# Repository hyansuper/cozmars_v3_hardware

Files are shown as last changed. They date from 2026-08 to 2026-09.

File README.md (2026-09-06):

- 3D model online preview: https://a360.co/4c95q6T
- PCB schematic and layout: https://oshwhub.com/hyan/project_uewvqdli
    - the antenna is not tuned for optimal, but it works somehow
    - PCB is 4-layered, 1.2 mm thick
- Electronics:
    - 头部主控是 ESP32-S3R8，底板 ESP32-C3N4 辅助，USB 正反接分别连接两个芯片
    - PCB 间用 SH1.0mm 导线连接，有些是两头同向，有些是两头反向，注意看 PCB 自行判断
    - 普通蓝色 180° 舵机，把两耳朵剪掉
    - GM12-N10 马达，短轴
    - 后轮用 8x4x14mm 轴承
    - GC0308 摄像头，其他型号因该也可以用，推荐 120° 广角
    - 50x30x40 锂电池，注意正负极
    - 3012 小扬声器

TODO: 
    use shorter wires and smaller connectors for the servos

LICENSE: TAPR Open Hardware License

firmware: https://github.com/hyansuper/cozmars.git

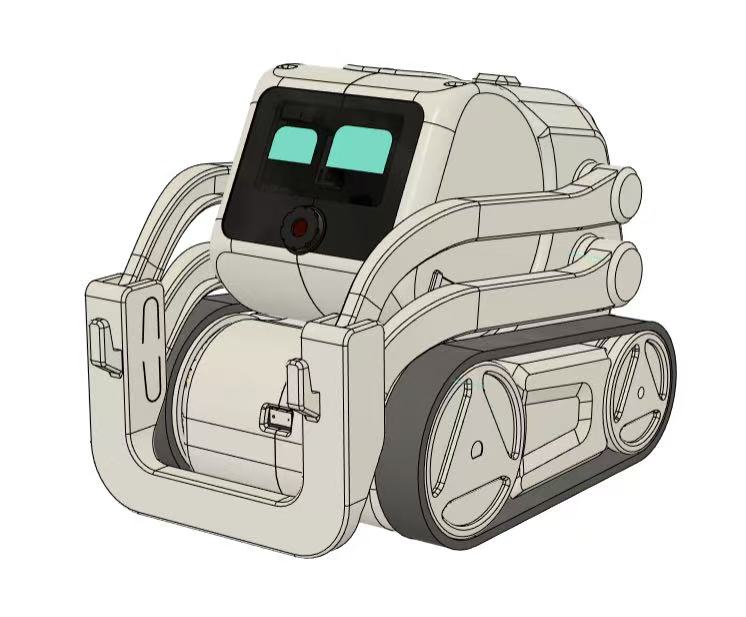
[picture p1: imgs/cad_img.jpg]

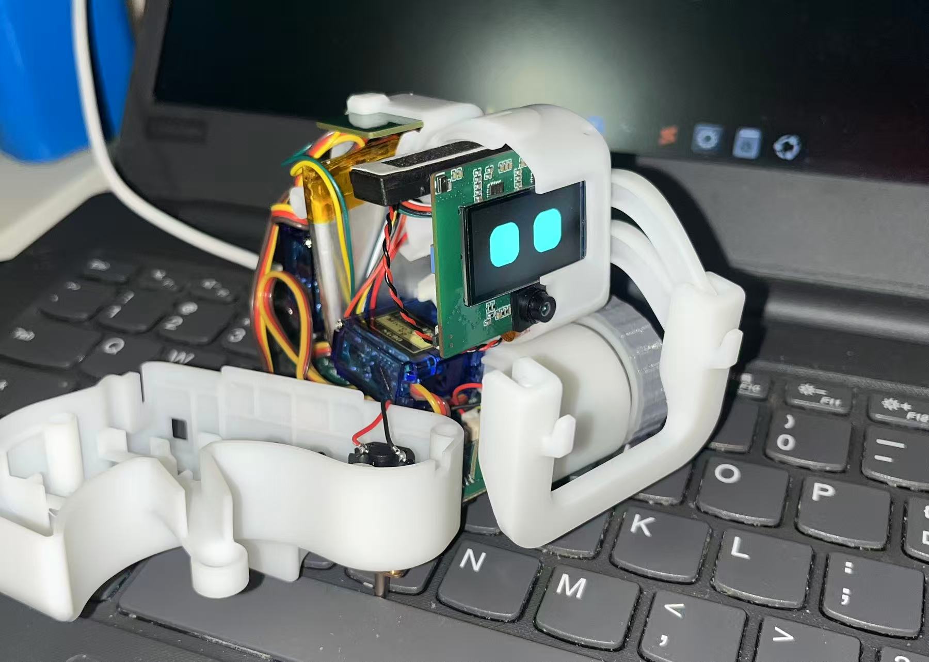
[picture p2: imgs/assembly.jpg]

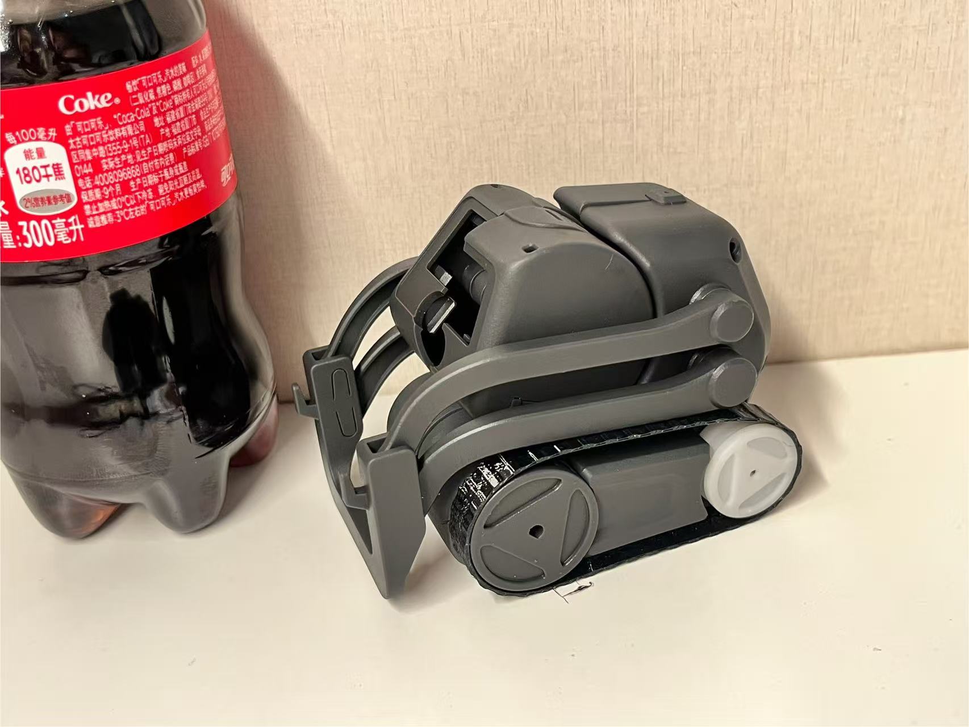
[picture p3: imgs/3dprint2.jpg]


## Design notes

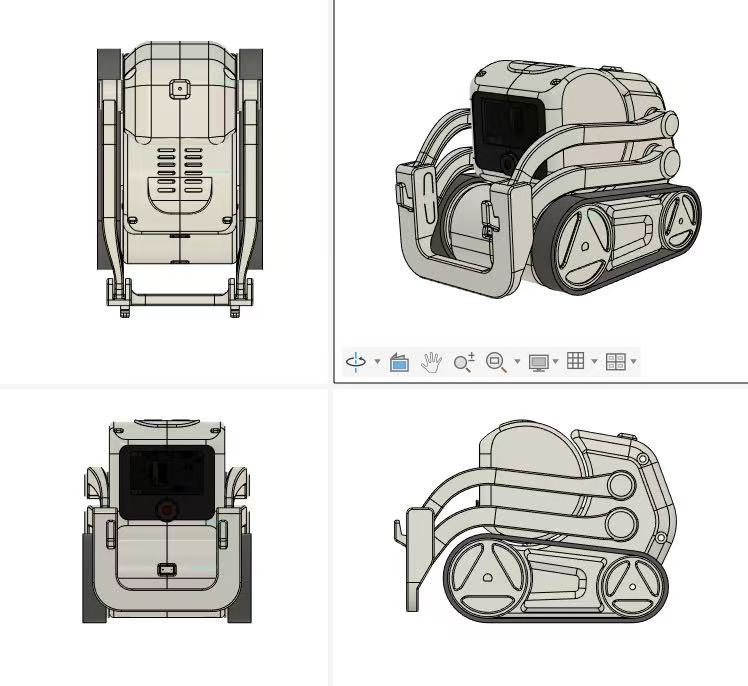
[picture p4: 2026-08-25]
imgs/cad_img3.jpg

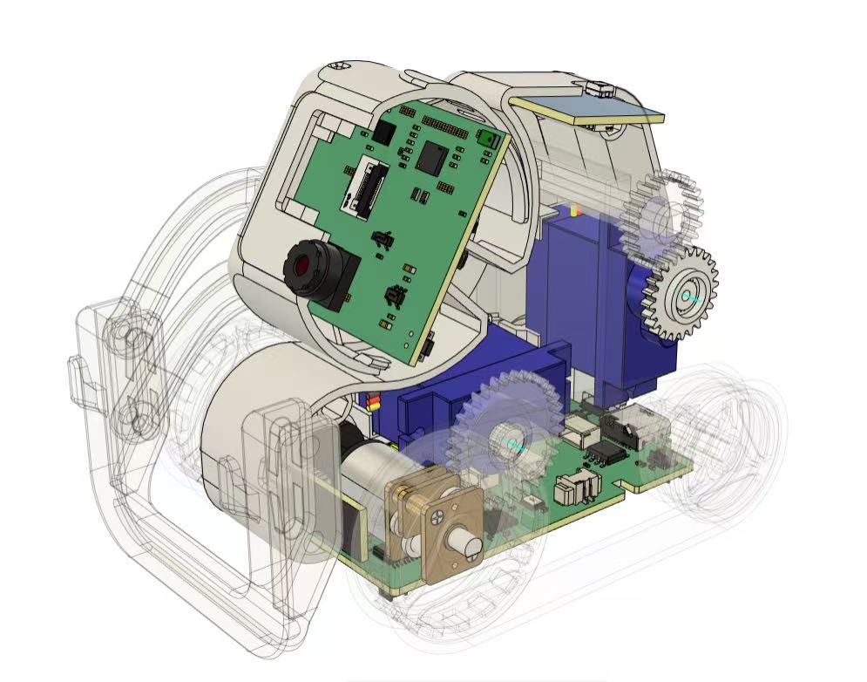
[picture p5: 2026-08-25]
imgs/cad_img2.jpg

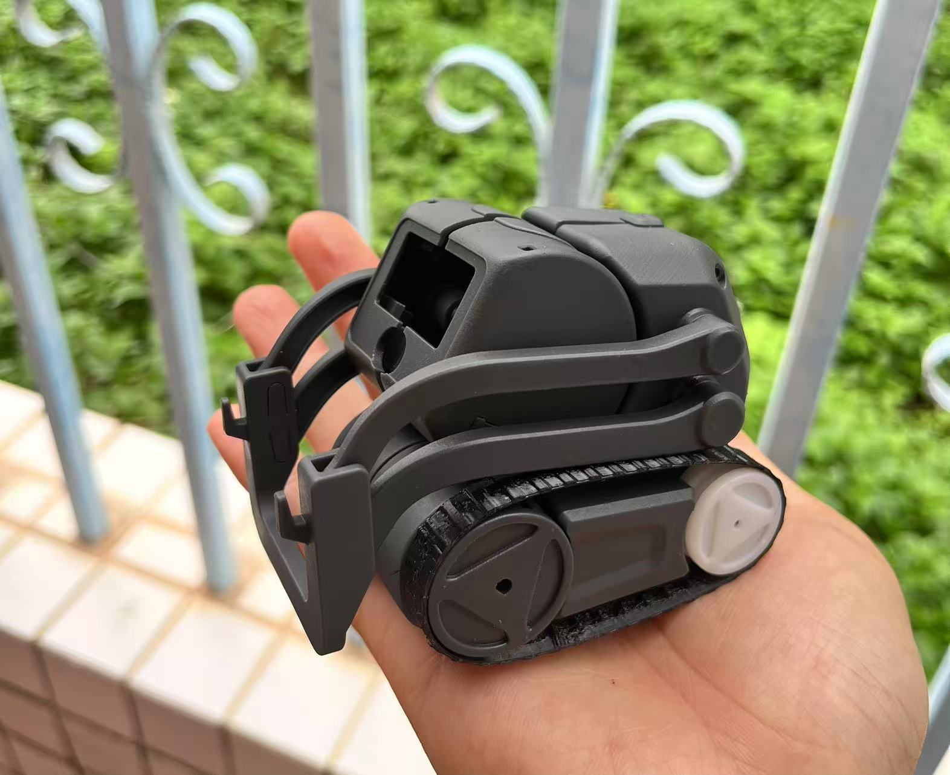
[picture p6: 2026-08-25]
imgs/3dprint.jpg

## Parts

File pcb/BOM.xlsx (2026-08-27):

No. | Quantity | Comment | Designator | Footprint | Value | Manufacturer Part | Manufacturer | Supplier Part | Supplier | Add into BOM
1 | 1 | 8.2pF | C1 | C0402 | 8.2pF | 0402CG8R2C500NT | FH(风华) | C1579 | LCSC | yes
2 | 37 | 100nF | C2,C6,C11,C12,C13,C16,C18,C24,C26,C27,C41,C47,C48,C52,C54,C56,C62,C63,C71,C72,C76,C81,C82,C89,C90,C94,C96,C97,C100,C108,C109,C112,C117,C118,C122,C123,C124 | C0402 | 100nF |  |  |  |  | yes
3 | 4 | 10pF | C3,C4,C92,C93 | C0402 | 10pF |  |  |  |  | yes
4 | 39 | 1uF | C5,C7,C10,C14,C15,C19,C20,C21,C22,C23,C25,C28,C29,C30,C31,C32,C33,C34,C35,C36,C37,C38,C39,C42,C43,C44,C45,C46,C49,C55,C57,C64,C66,C69,C83,C95,C99,C101,C125 | C0402 | 1uF |  |  |  |  | yes
5 | 8 | 22pF | C8,C17,C58,C59,C67,C68,C77,C114 | C0402 | 22pF |  |  |  |  | yes
6 | 19 | 10uF | C9,C40,C65,C70,C73,C74,C75,C78,C79,C80,C98,C104,C105,C106,C110,C111,C113,C115,C120 | C0603 | 10uF |  |  |  |  | yes
7 | 6 | 4.7uF | C50,C51,C53,C107,C121,C130 | C0402 | 4.7uF |  |  |  |  | yes
8 | 8 | 1nF | C60,C61,C84,C85,C86,C87,C88,C91 | C0402 | 1nF |  |  |  |  | yes
9 | 2 | 47uF | C102,C103 | CASE-B_3528 | 47uF | TAJB107K006RNJ | Kyocera AVX |  | LCSC | yes
10 | 1 | 10nF | C116 | C0402 | 10nF |  |  |  |  | yes
11 | 1 | 2.2nF | C119 | C0402 | 2.2nF |  |  |  |  | yes
12 | 1 | WAFER-SH1.0-6PWB | CN1 | CONN-SMD_6P-P1.00_XUNPU_WAFER-SH1.0-6PWB |  | WAFER-SH1.0-6PWB | XUNPU(讯普) | C3029345 | LCSC | yes
13 | 1 | DSK34 | D1 | SOD-123_L2.8-W1.8-LS3.7-RD |  | DSK34 | MDD | C41029 | LCSC | yes
14 | 1 | AFC01-S08FCA-00 | FPC1 | FPC-SMD_P0.50-8P_FGS-XJ-H2.0 |  | AFC01-S08FCA-00 | JS(钜硕电子) | C262657 | LCSC | yes
15 | 1 | AFC01-S24FCA-00 | FPC4 | FPC-SMD_24P-P0.50_AFC01-S24FCA-00 |  | AFC01-S24FCA-00 | JS(钜硕电子) | C262669 | LCSC | yes
16 | 2 | PZ254RS-11-03P-01 | H1,H2 | HDR-SMD_PZ254RS-11-03P-01 |  | PZ254RS-11-03P-01 | XFCN(兴飞) | C52191415 | LCSC | yes
17 | 1 | 1.3nH | L1 | L0402-RD | 1.3nH | SDCL1005C1N3STDF | Sunlord(顺络) | C279756 | LCSC | yes
18 | 1 | 39nH | L2 | L0402 | 39nH | SDCL1005C39NJTDF | Sunlord(顺络) | C26443 | LCSC | yes
19 | 2 | 24nH | L3,L6 | L0402-RD | 24nH | SDCL1005C24NJTDF | Sunlord(顺络) | C74301 | LCSC | yes
20 | 2 | 2nH | L4,L7 | L0402 | 2nH | LQG15HS2N0S02D | muRata(村田) | C18216 | LCSC | yes
21 | 2 | 2.2uH | L5,L8 | IND-SMD_L3.0-W3.0_FNR30XXS | 2.2uH | FNR3015S2R2MT | cjiang(长江微电) | C167747 | LCSC | yes
22 | 1 | XL-3528RGBW-WS2812B | LED1 | LED-SMD_4P-L3.5-W2.8-BR-1 |  | XL-3528RGBW-WS2812B | XINGLIGHT(成兴光) | C2890364 | LCSC | yes
23 | 2 | ZTS6216 | MIC1,MIC2 | MIC-SMD_4P-L2.8-W1.9-P1.84-TL |  | ZTS6216 | ZILLTEK(钰太) | C481302 | LCSC | yes
24 | 3 | AO3401A | Q1,Q2,Q3 | SOT-23_L2.9-W1.3-P1.90-LS2.4-BR |  | AO3401A | AOS | C15127 | LCSC | yes
25 | 14 | 100K | R1,R4,R7,R13,R16,R19,R20,R21,R23,R25,R26,R27,R28,R36 | R0402 | 100K |  |  |  |  | yes
26 | 7 | 10K | R2,R17,R18,R41,R42,R46,R49 | R0402 | 10K |  |  |  |  | yes
27 | 7 | 75R | R3,R9,R12,R30,R31,R32,R39 | R0402 | 75R |  |  |  |  | yes
28 | 5 | 4.7K | R5,R10,R11,R24,R40 | R0402 | 4.7K |  |  |  |  | yes
29 | 9 | 22K | R6,R8,R14,R15,R22,R29,R33,R37,R38 | R0402 | 22K |  |  |  |  | yes
30 | 2 | 5.1K | R34,R35 | R0402 | 5.1K |  |  |  |  | yes
31 | 1 | 1K | R50 | R0402 | 1K |  |  |  |  | yes
32 | 2 | TS24CA | SW1,SW2 | SW-SMD_2P-TS24CA |  | TS24CA | SHOU HAN(首韩) | C393942 | LCSC | yes
33 | 6 | ITR1502SR40A/TR8 | SW3,SW4,SW5,SW6,SW7,SW8 | SW-SMD_4P-L4.0-W3.0_ITR1502SR40A-TR8 |  | ITR1502SR40A/TR8 | EVERLIGHT(台湾亿光) | C183793 | LCSC | yes
34 | 1 | MSK12C02-BB2.5 | SW9 | SW-SMD_MSK12C02G25-B |  | MSK12C02-BB2.5 | SHOU HAN(首韩) | C47020938 | LCSC | yes
35 | 2 | TS-1187A-B-A-B | SW10,SW11 | SW-SMD_4P-L5.1-W5.1-P3.70-LS6.5-TL_H1.5 |  | TS-1187A-B-A-B | XKB Connection(中国星坤) | C318884 | LCSC | yes
36 | 1 | RFANT5220110A0T | U1 | FILTER-SMD_L5.2-W2.0-L |  | RFANT5220110A0T | Walsin(华新科) | C127611 | LCSC | yes
37 | 1 | ESP32-S3R8 | U2 | QFN-56_L7.0-W7.0-P0.40-TL-EP4.0 |  | ESP32-S3R8 | ESPRESSIF(乐鑫) | C2913194 | LCSC | yes
38 | 1 | ES7210 | U3 | QFN-32_L4.0-W4.0-P0.40-BL-EP2.7 |  | ES7210 | Everest-semi(顺芯) | C365743 | LCSC | yes
39 | 1 | BM06B-SRSS-TB(LF)(SN) | U4 | CONN-SMD-6P-P1.00_BM06B-SRSS-TB-LF-SN |  | BM06B-SRSS-TB(LF)(SN) | JST | C160392 | LCSC | yes
40 | 1 | W25Q128JVSIQ | U5 | SOIC-8_L5.3-W5.3-P1.27-LS8.0-BL |  | W25Q128JVSIQ | WINBOND(华邦) | C97521 | LCSC | yes
41 | 1 | ES8311 | U6 | WQFN-20_L3.0-W3.0-P0.40-BL-EP1.7 |  | ES8311 | Everest-semi(顺芯) | C962342 | LCSC | yes
42 | 1 | NS4150B | U7 | MSOP-8_L3.0-W3.0-P0.65-LS5.0-BL |  | NS4150B | Nsiway(纳芯威) | C189961 | LCSC | yes
43 | 1 | ME6211C28M5G-N | U8 | SOT-23-5_L3.0-W1.7-P0.95-LS2.8-BR |  | ME6211C28M5G-N | MICRONE(南京微盟) | C53099 | LCSC | yes
44 | 2 | SY8088AAC | U9,U13 | SOT-23-5_L3.0-W1.7-P0.95-LS2.8-BR |  | SY8088AAC | silergy(矽力杰) | C79313 | LCSC | yes
45 | 1 | ME6211C15M5G-N | U10 | SOT-23-5_L3.0-W1.7-P0.95-LS2.8-BR |  | ME6211C15M5G-N | MICRONE(南京微盟) | C53100 | LCSC | yes
46 | 4 | WAFER-MX1.25-2PWB | U11,U16,U17,U24 | CONN-SMD_2P-P1.25_XUNPU_WAFER-MX1.25-2PWB |  | WAFER-MX1.25-2PWB | XUNPU(讯普) | C3029359 | LCSC | yes
47 | 2 | 40MHz | U12,X1 | CRYSTAL-SMD_4P-L2.5-W2.0-BL | 40MHz | X252040MMB4SI | YXC(扬兴晶振) | C2885592 | LCSC | yes
48 | 4 | ZX-SH1.0-4PWT | U14,U15,U26,U27 | CONN-SMD_4P-P1.00_MEGASTAR_ZX-SH1.0-4PWT |  | ZX-SH1.0-4PWT | Megastar(兆星) | C7430446 | LCSC | yes
49 | 1 | ESD5451N | U18 | X1-DFN1006-2_L1.0-W0.6-P0.65-BI |  | ESD5451N | TECH PUBLIC(台舟) | C2936977 | LCSC | yes
50 | 2 | TC118S | U19,U21 | SOP-8_L4.9-W3.9-P1.27-LS6.0-BL |  | TC118S | FM富满 | C88308 | LCSC | yes
51 | 1 | 74HC165PW,118 | U20 | TSSOP-16_L5.0-W4.4-P0.65-LS6.4-BL |  | 74HC165PW,118 | Nexperia(安世) | C80696 | LCSC | yes
52 | 1 | ESP32-C3FN4 | U22 | QFN-32_L5.0-W5.0-P0.50-BL-EP3.7 |  | ESP32-C3FN4 | ESPRESSIF(乐鑫) | C2848860 | LCSC | yes
53 | 1 | TC4056A | U23 | ESOP-8_L4.9-W3.9-P1.27-LS6.0-BR-EP3.3 |  | TC4056A | FM(富满) | C84051 | LCSC | yes
54 | 1 | VL53L0CXV0DH/1 | U25 | OPTO-SMD_12P_VL53L0CXV0DH-1 |  | VL53L0CXV0DH/1 | ST(意法半导体) | C91199 | LCSC | yes
55 | 1 | TC233A | U28 | SOT-23-6_L2.9-W1.6-P0.95-LS2.8-BL |  | TC233A | FM富满 | C2798022 | LCSC | yes
56 | 1 | MPU-6050 | U29 | QFN-24_L4.0-W4.0-P0.50-BL-EP2.7 |  | MPU-6050 | TDK InvenSense(应美盛) | C24112 | LCSC | yes
57 | 1 | TYPE-C16PIN | USB1 | USB-C-SMD_TYPE-C16PIN |  | TYPE-C16PIN | SHOU HAN(首韩) | C393939 | LCSC | yes

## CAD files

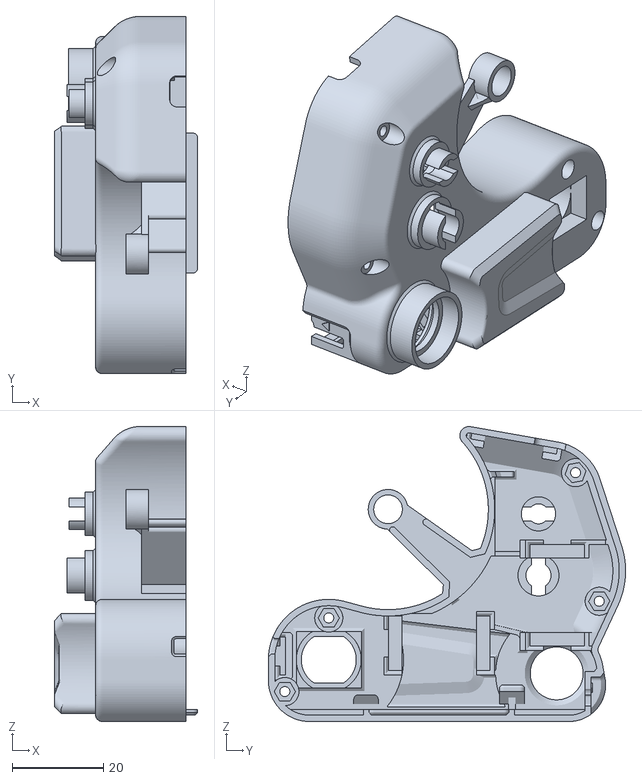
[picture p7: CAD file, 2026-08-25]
stl/Body2.stl
31.4 x 78.4 x 64.7

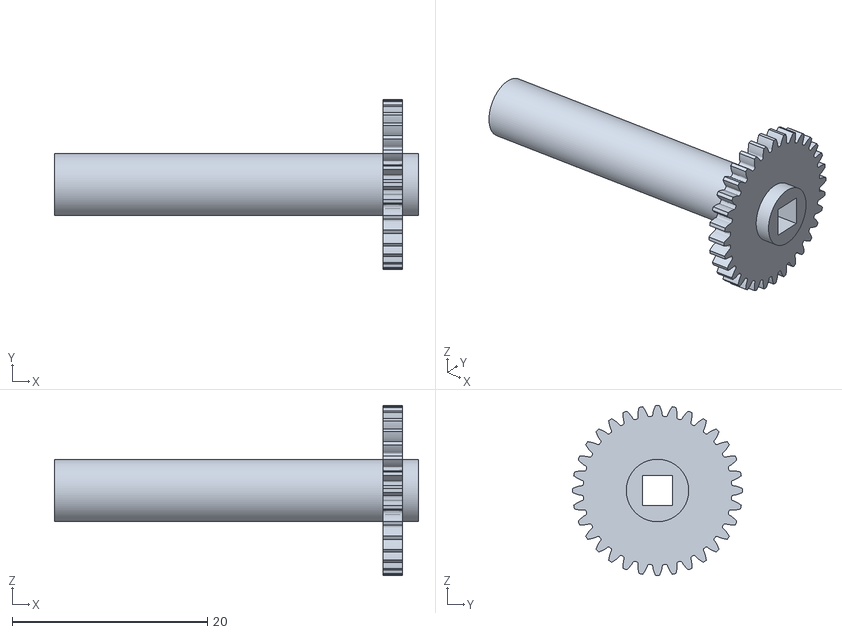
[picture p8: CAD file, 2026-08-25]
stl/LiftGear2.stl
37.3 x 17.4 x 17.4

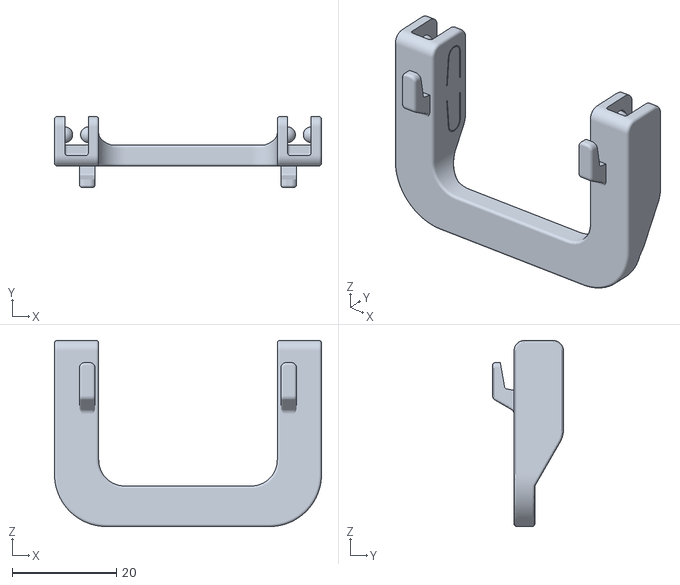
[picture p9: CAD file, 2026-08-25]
stl/Lift5.stl
51.3 x 13.6 x 35.8

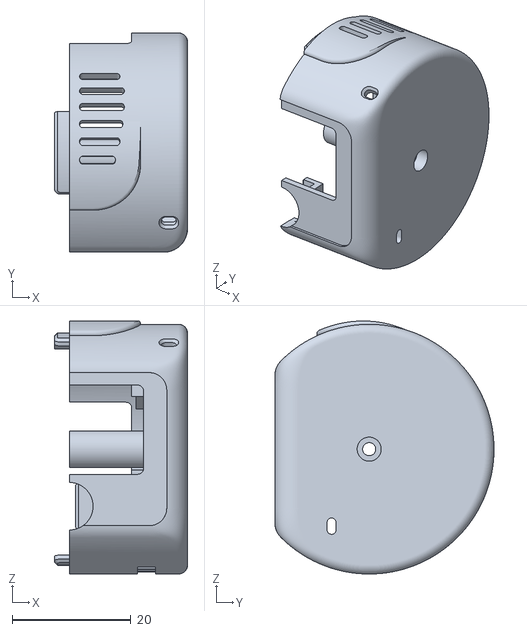
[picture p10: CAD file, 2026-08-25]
stl/Head1.stl
22.4 x 36.8 x 42.6

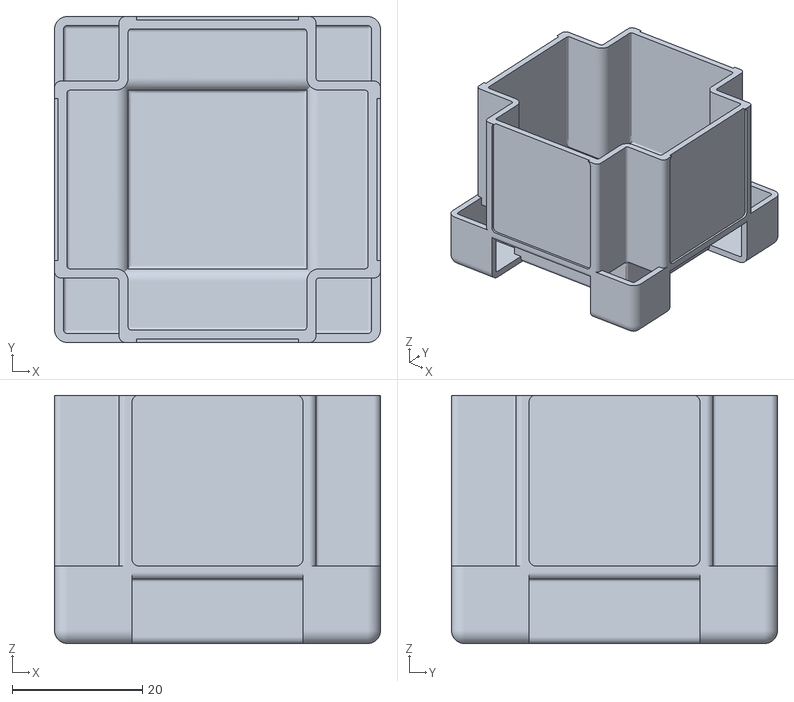
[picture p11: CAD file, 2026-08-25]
stl/Cube2.stl
50.0 x 50.0 x 38.0

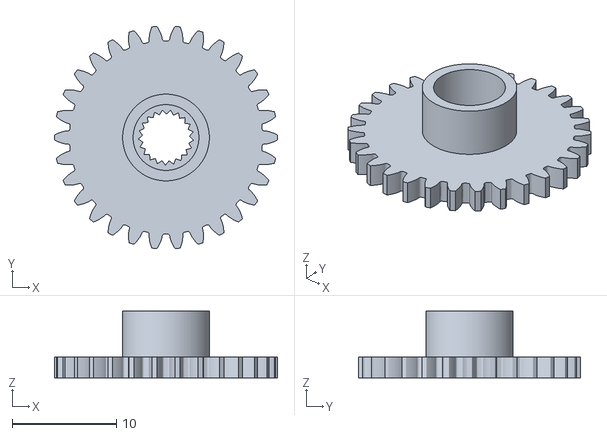
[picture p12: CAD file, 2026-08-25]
stl/HeadGear.stl
21.3 x 21.3 x 6.38

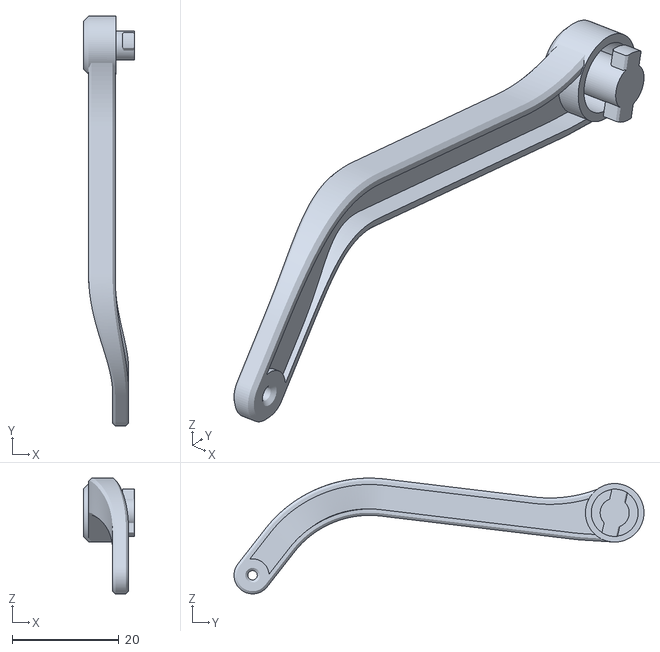
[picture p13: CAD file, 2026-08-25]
stl/Lift4.stl
9.65 x 77.0 x 21.7

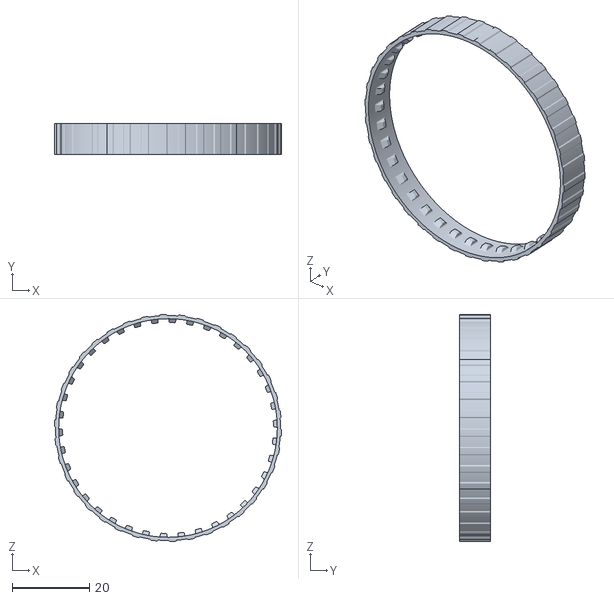
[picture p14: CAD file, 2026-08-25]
stl/Tread_x2(TPU).stl
58.9 x 8.00 x 58.9

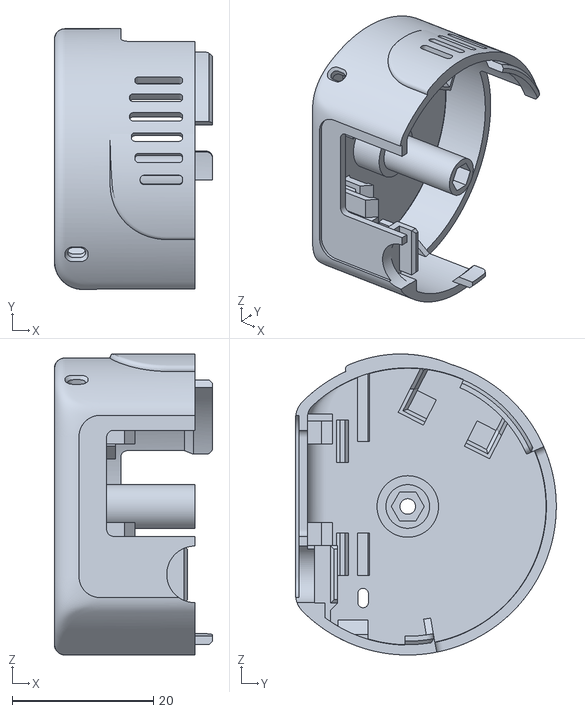
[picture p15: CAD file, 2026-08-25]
stl/Head2.stl
22.4 x 36.8 x 42.6

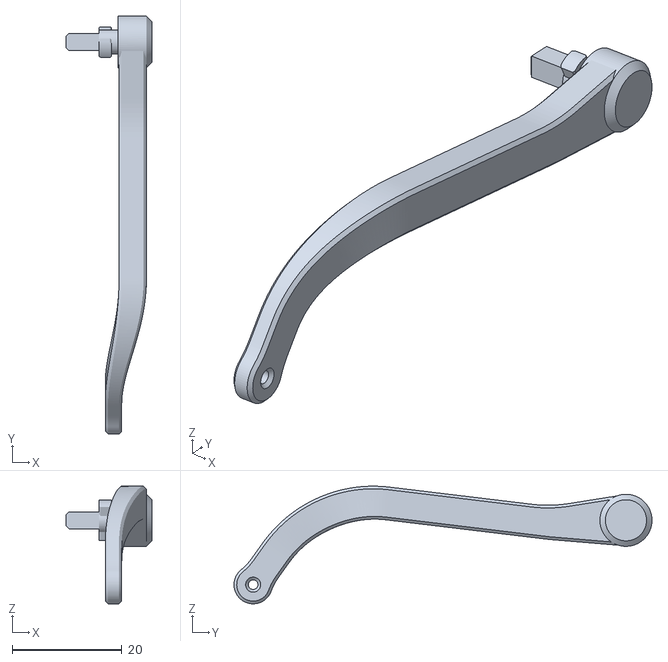
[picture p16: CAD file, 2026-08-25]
stl/Lift1.stl
15.6 x 76.2 x 21.5

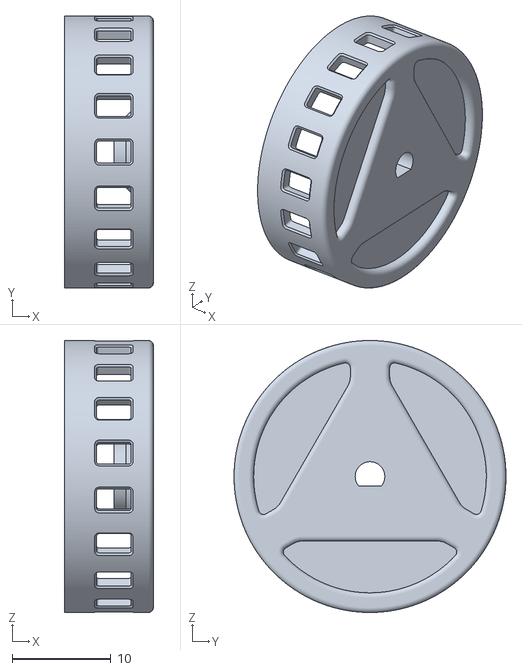
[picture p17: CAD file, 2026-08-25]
stl/Wheel1_x2.stl
9.00 x 27.6 x 27.6

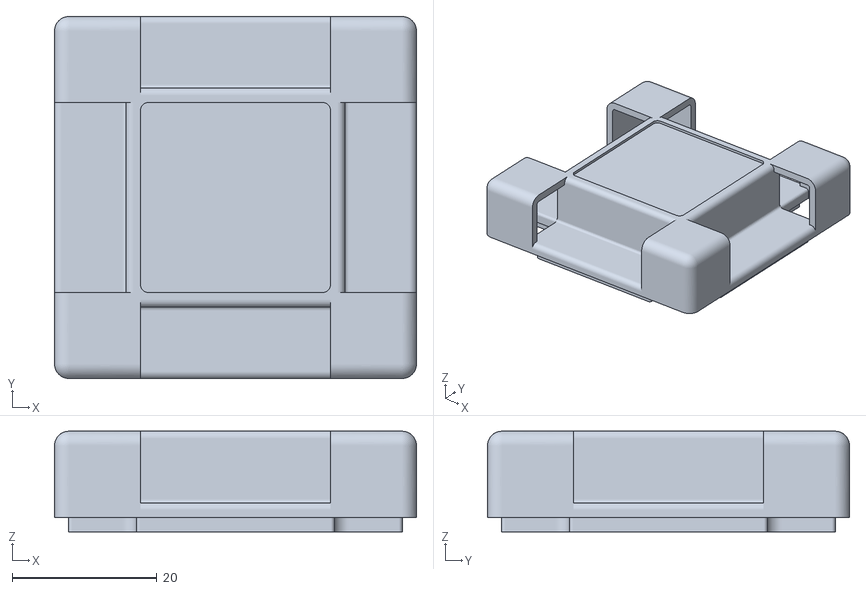
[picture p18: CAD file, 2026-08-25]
stl/Cube1.stl
50.0 x 50.0 x 13.9

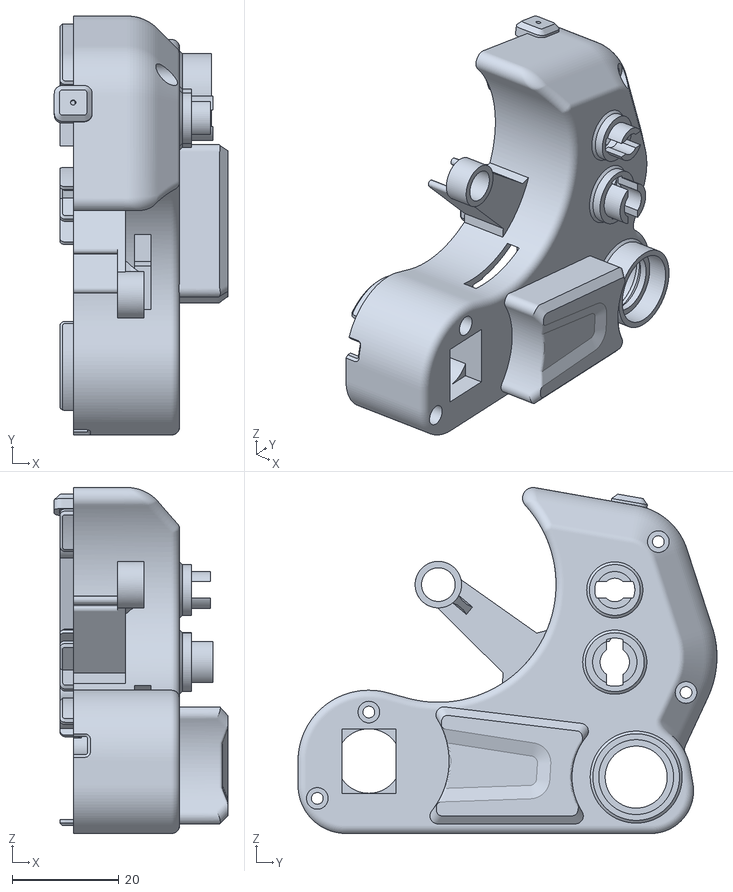
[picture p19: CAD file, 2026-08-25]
stl/Body1.stl
32.4 x 78.4 x 64.7

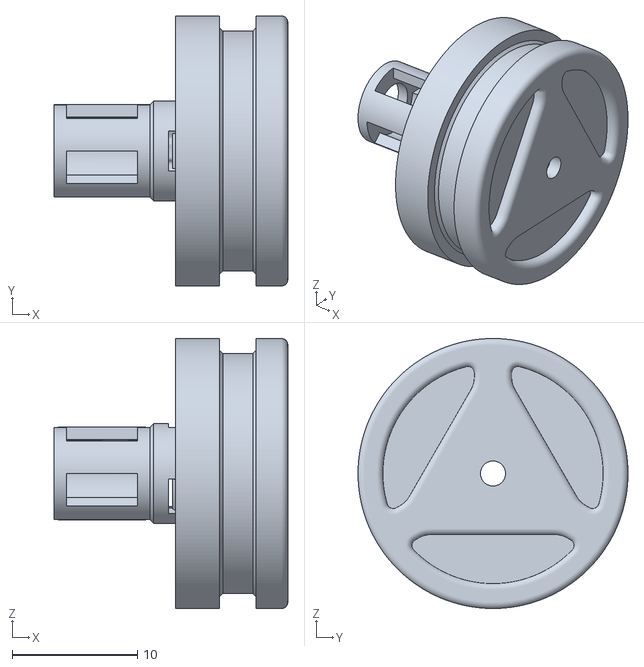
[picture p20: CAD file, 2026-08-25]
stl/Wheel2_x2.stl
18.7 x 21.6 x 21.6

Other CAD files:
stl/Lift3.stl
stl/Lift2.stl
stl/LiftGear1.stl
cube.f3d
tread.f3d

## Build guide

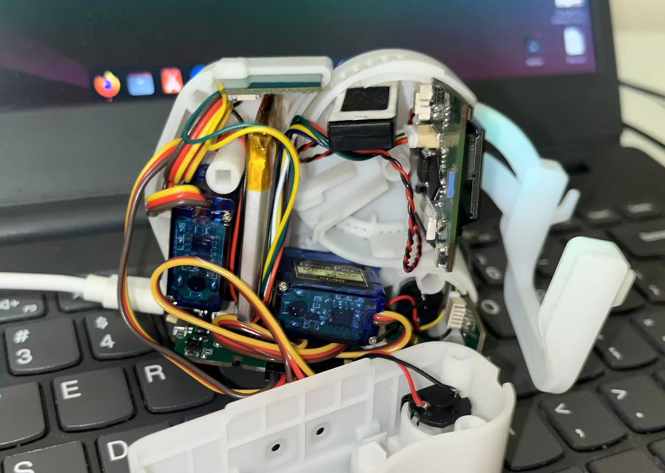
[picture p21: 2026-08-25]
imgs/assembly2.jpg

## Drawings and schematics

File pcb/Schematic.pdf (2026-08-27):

# Codec

# ESP32S3R8

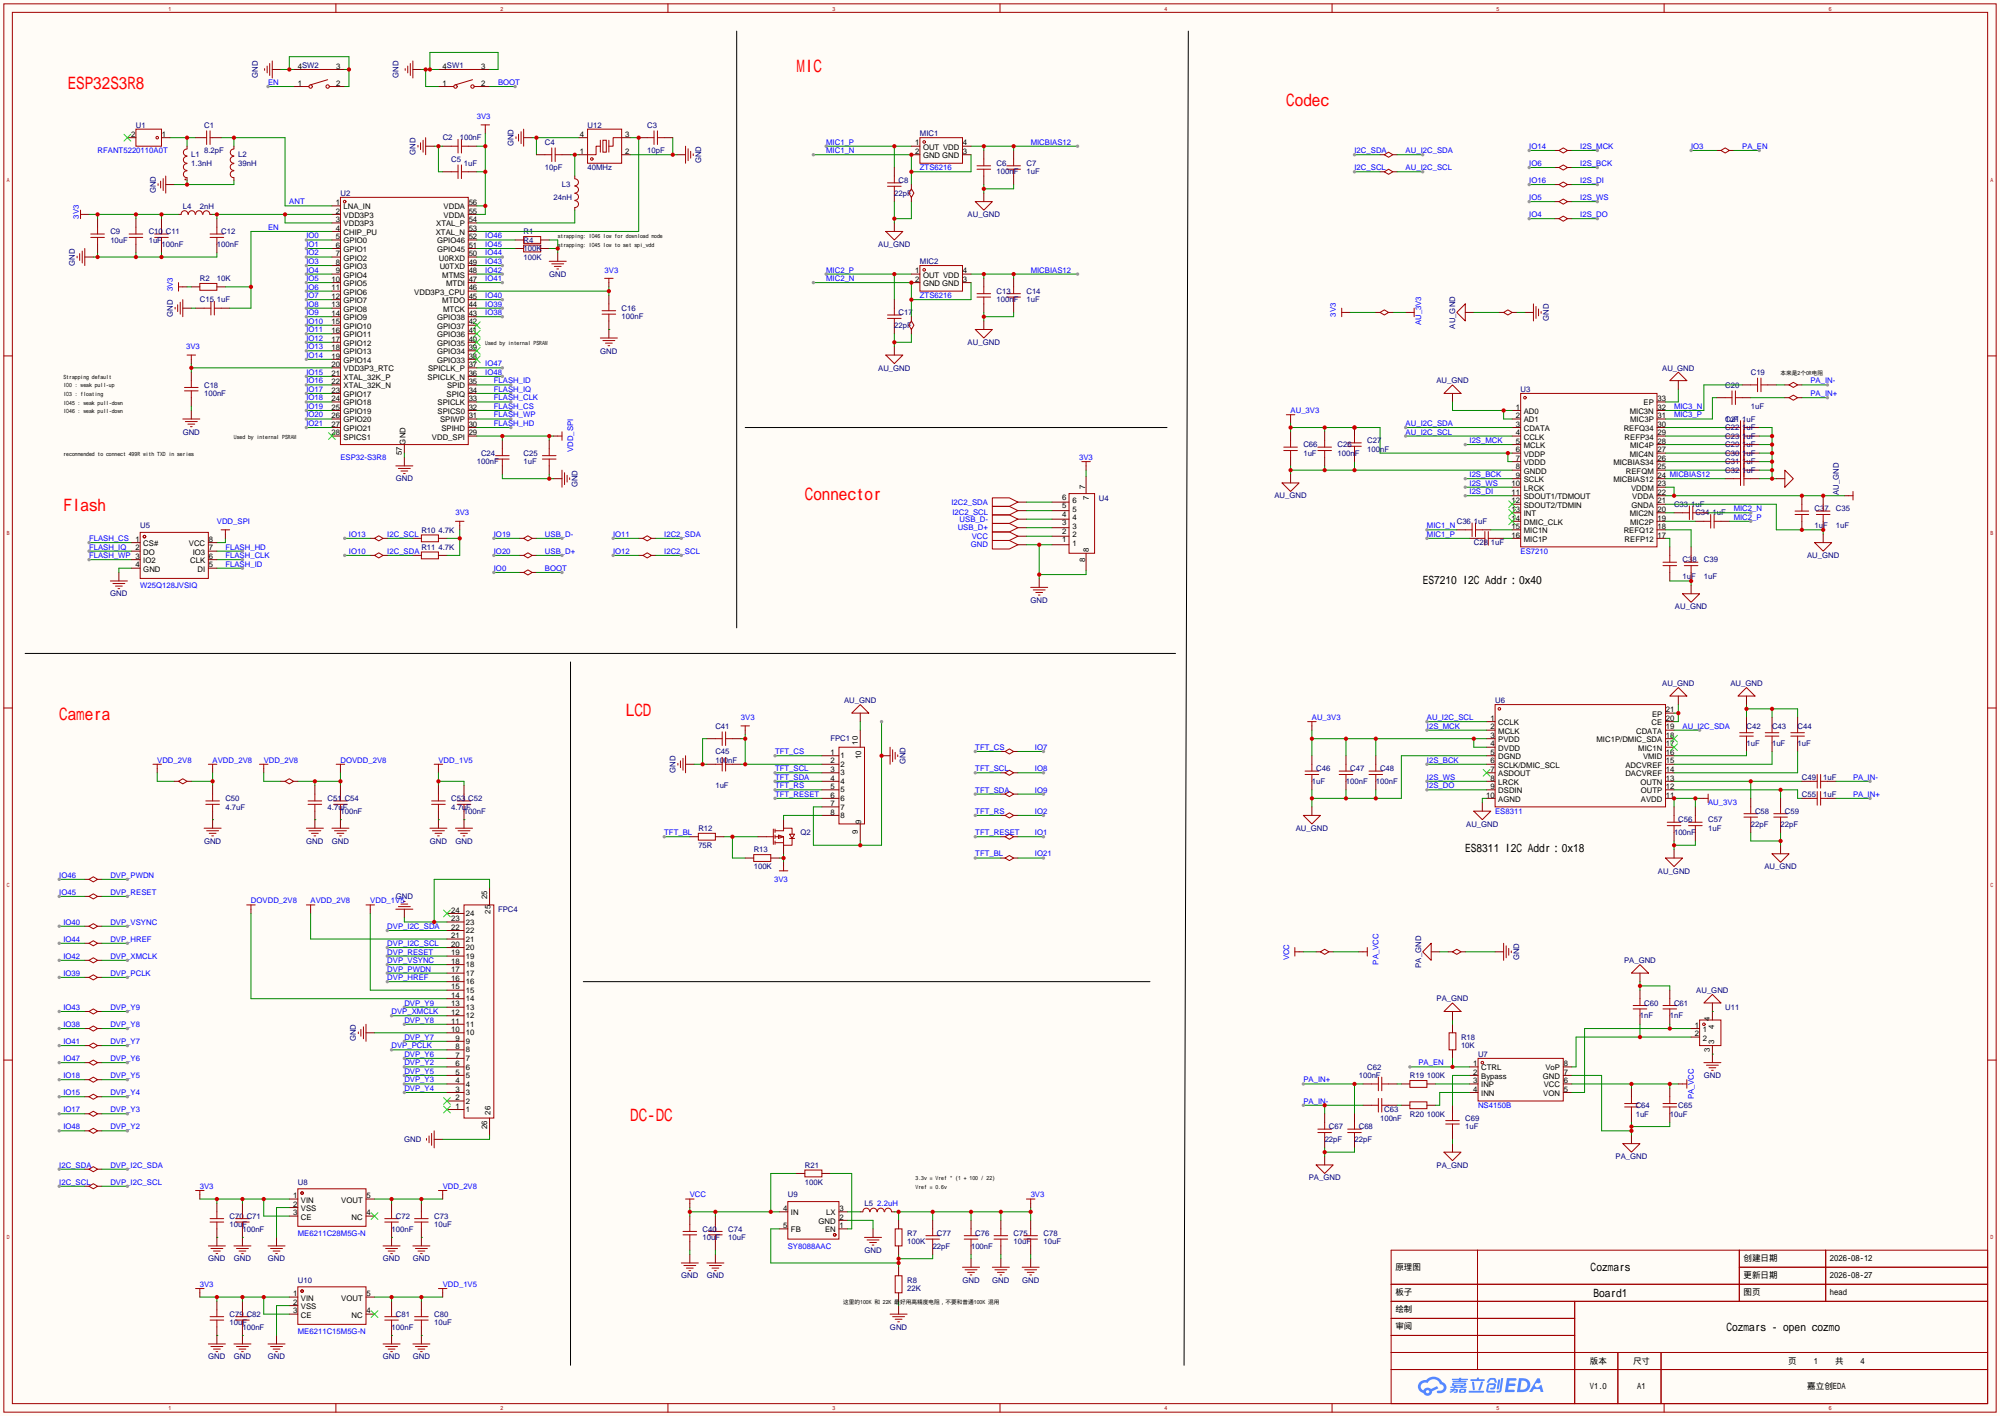
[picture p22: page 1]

strapping: IO46 low for download mode
strapping: IO45 low to set spi_vdd

Used by internal PSRAM

recommended to connect 499R with TXD in series

原理图 | Cozmars | 创建日期 | 2026-08-12

更新日期 | 2026-08-27

板子 | Board1 | 图页 | head

V1.0 | A1 | 嘉立创EDA

# DS 10 D0 11 D1 12 D2 13 D3 14 CE# 15 VCC 16

# ESP32C3FN4

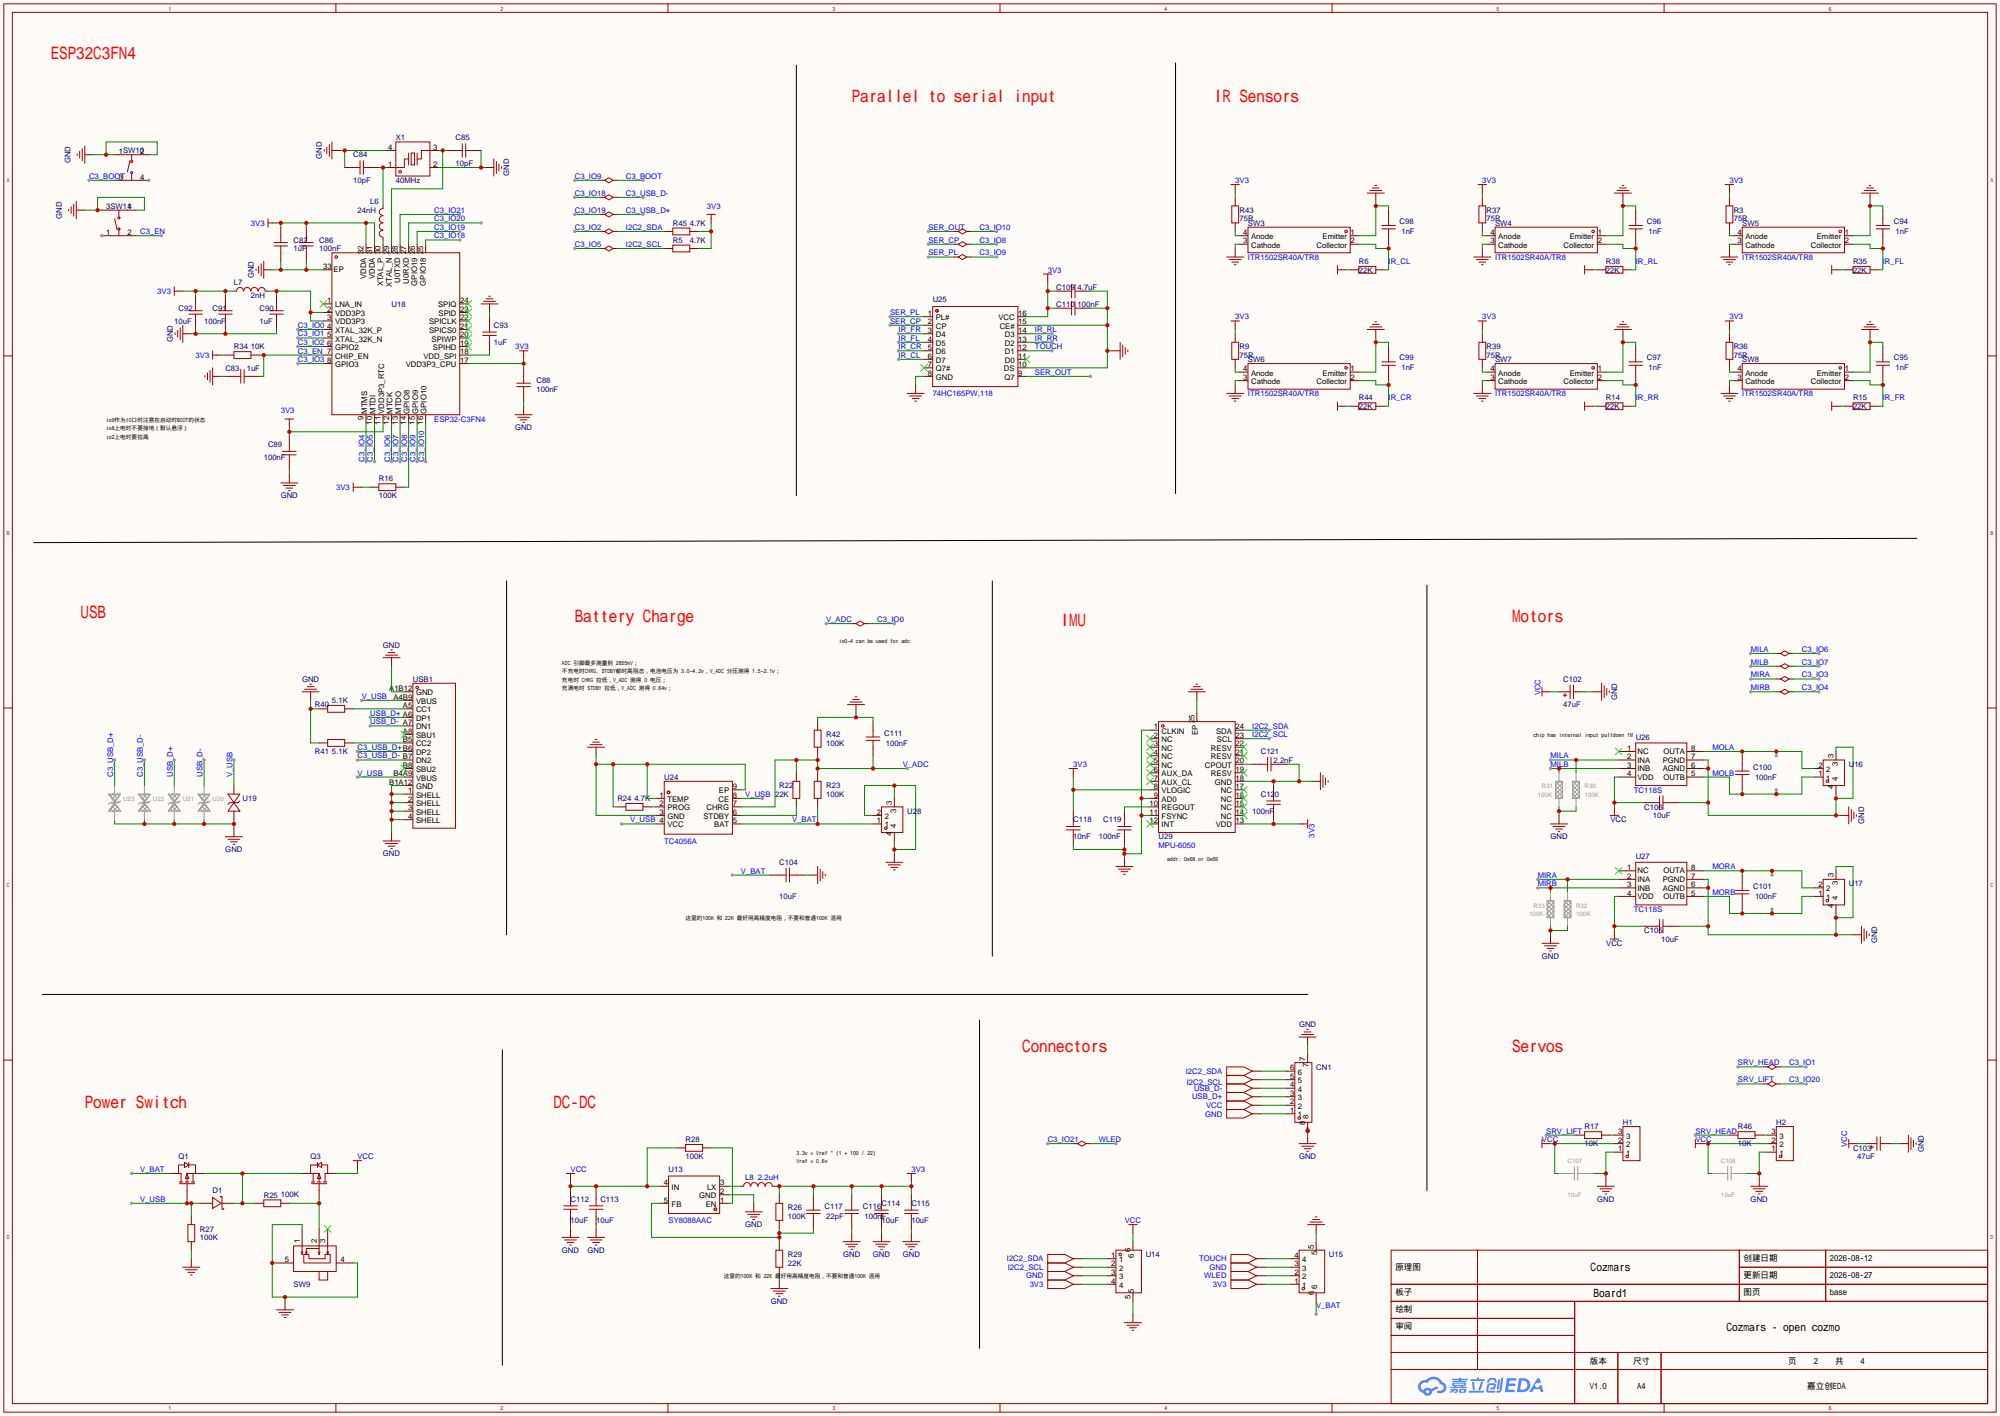
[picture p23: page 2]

VDD3P3_CPU 17 VDD_SPI 18 SPIHD 19 SPIWP 20 SPICS0 21 SPICLK 22 SPID 23 SPIQ 24 GPIO¹⁸ ²⁵ GPIO¹⁹ ²⁶ U⁰RXD ²⁷

io0~4 can be used for adc

ADC 引脚最多测量到 2855mV；
不充电时CHRG、STDBY都时高阻态，电池电压为 3.0~4.2v，V_ADC 分压测得 1.5~2.1v；
充电时 CHRG 拉低，V_ADC 测得 0 电压；
充满电时 STDBY 拉低，V_ADC 测得 0.64v；

chip has internal input pulldown 1M
MILA
MILB

原理图 | Cozmars | 创建日期 | 2026-08-12

更新日期 | 2026-08-27

板子 | Board1 | 图页 | base

绘制 | | Cozmars - open cozmo
审阅

V1.0 | A4 | 嘉立创EDA

# TOF

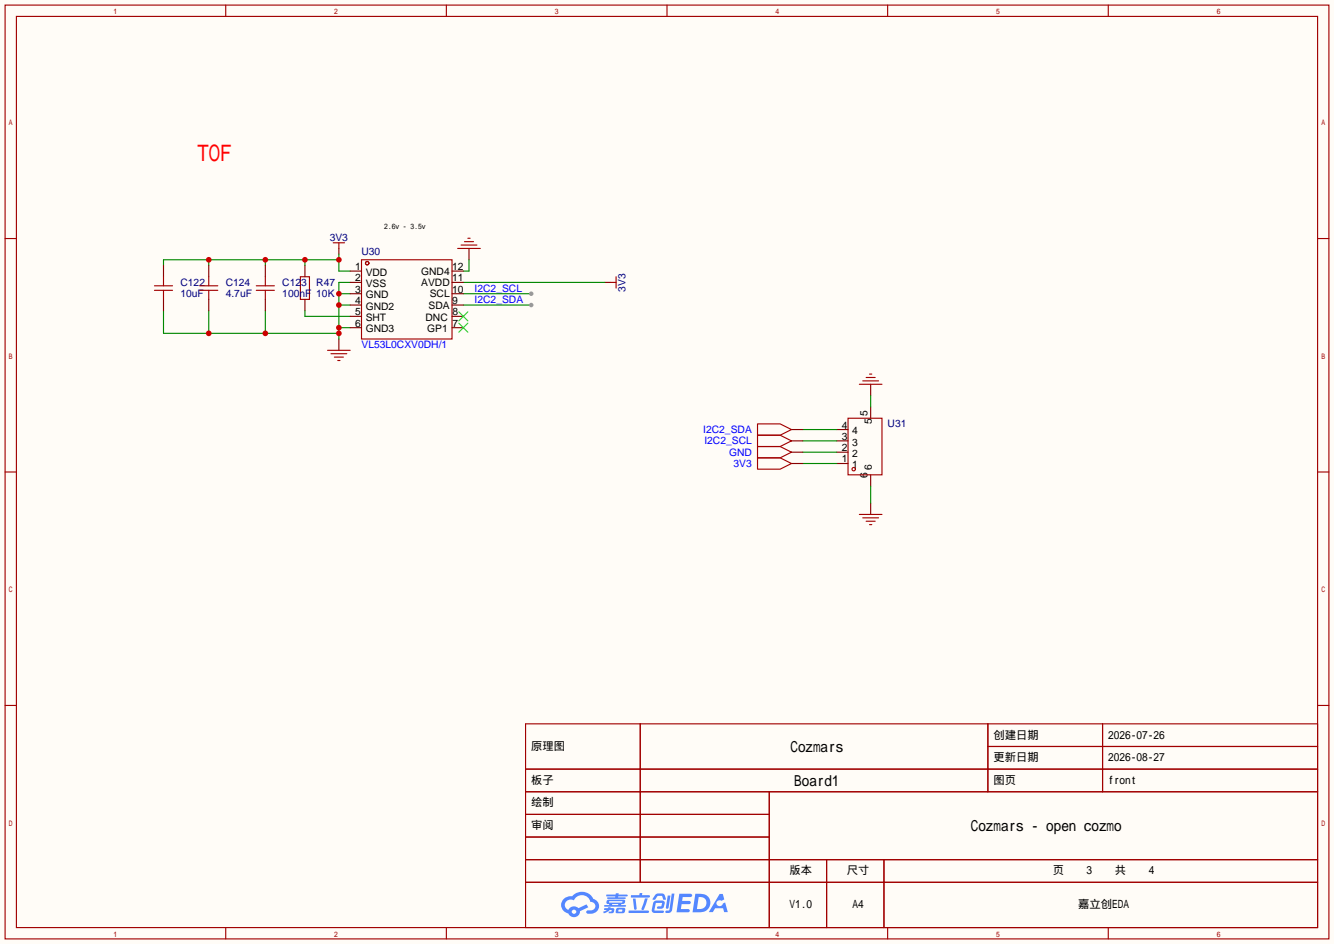
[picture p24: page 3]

原理图 | Cozmars | 创建日期 | 2026-07-26

更新日期 | 2026-08-27

板子 | Board1 | 图页 | front

绘制 | | Cozmars - open cozmo
审阅

Touch | LEDs

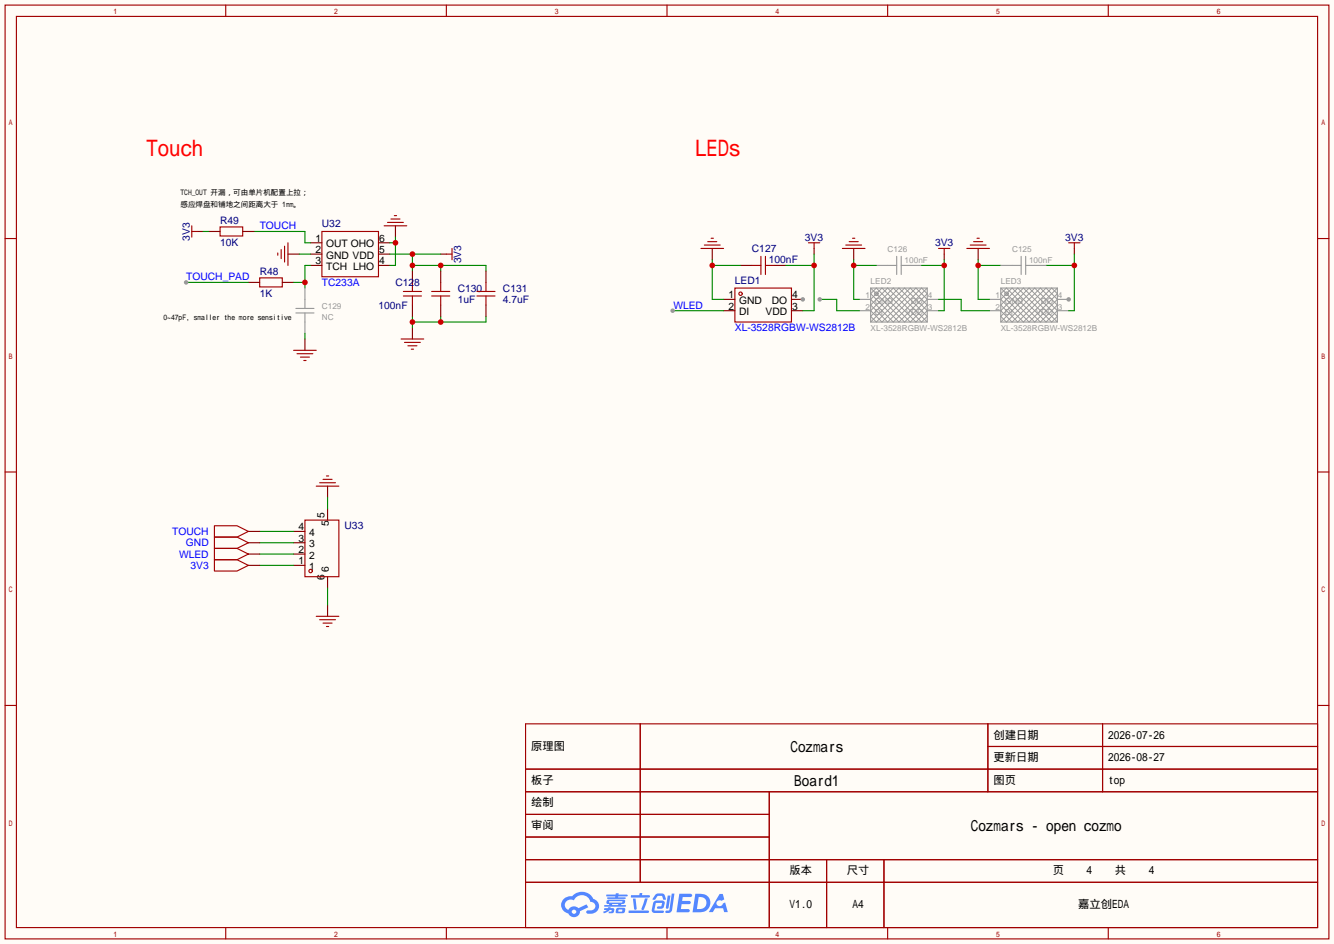
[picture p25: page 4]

0~47pF, smaller the more sensitive

原理图 | Cozmars | 创建日期 | 2026-07-26

更新日期 | 2026-08-27

板子 | Board1 | 图页 | top

绘制 | | Cozmars - open cozmo
审阅

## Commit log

2026-08-27 更新 README.md
2026-08-27 add pcb folder
    [BOM.xlsx, PickAndPlace.xlsx]
2026-09-06 add cube and tread model
    [cube.f3d, tread.f3d]
